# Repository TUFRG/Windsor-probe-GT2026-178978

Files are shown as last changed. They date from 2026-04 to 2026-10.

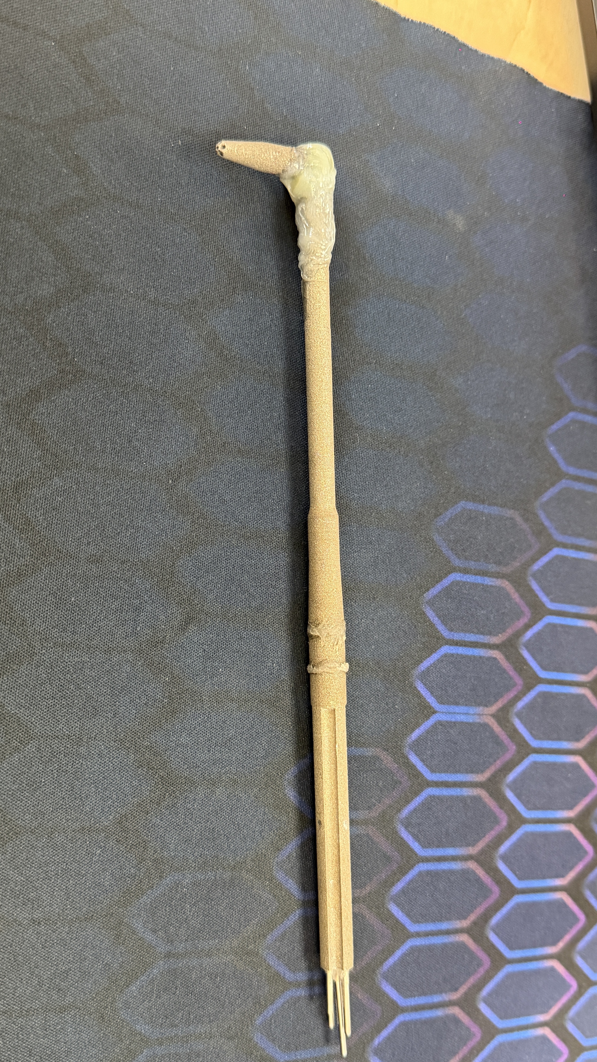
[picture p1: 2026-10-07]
Probe Calibration/Calibration Data and Map/ReMax On Axis Calibration - Use This/P2/Probe 2 Identifier.jpg

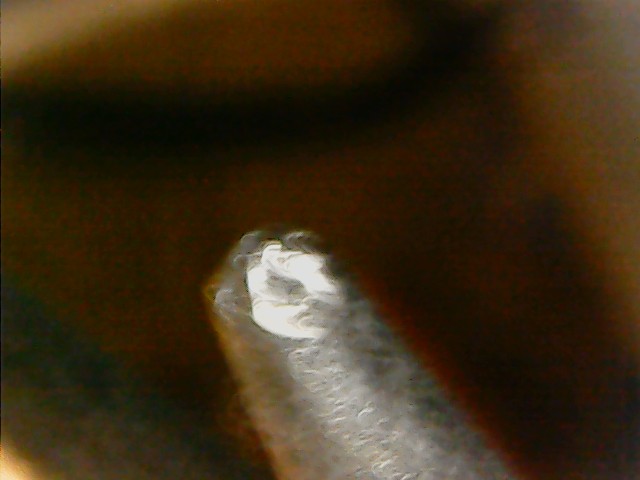
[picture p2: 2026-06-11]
Probe Design Files/Probe Assembly (CAT Parts and STL)/Digital Microscope Images/Probe 1 Photos/WIN_20260123_12_52_14_Pro.jpg

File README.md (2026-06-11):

# Windsor-probe-GT2026-178978

This repository contains openly available design and calibration files for the Windsor Probe—an L-shaped adaptation of the Oxford Probe head. The probe is an additively manufactured stainless steel five-hole probe featuring a 3mm probe head diameter, developed by Aman Thomson during his Masters degree with the Turbomachinery and Unsteady Flows Research Group, at the University of Windsor.

Probe calibration was performed using LabVIEW, with post-processing and data analysis conducted in Python, Excel, and MATLAB.

## Citing

Please cite the following paper, which details the design and calibration of the probe:

Thomson, A., Fontanin, L., and Defoe, J., “The Windsor Probe: An Additively Manufactured L-Shaped 5-Hole Probe Based on Oxford Probe Heads,” Proceedings of the ASME Turbo Expo, GT2026-178978, Milan, Italy, June 15–19, 2026.

## Contents

The repository is organized into three main folders: the first contains the probe design files, the second contains the calibration files, and the third contains the calibration facility design files together with the Bill of Materials (BOM).

### Probe Design Files

This section is organized into the following folders:

* **Drawings**

&#x09;  Includes detailed technical drawings for all probe components

* **Probe Assembly (CAT Parts and STL)**

&#x09;Provides individual CAD files for each probe component and the full assembly. This folder also includes high-resolution microscopic images of the assembled probe for inspection and reference.

&#x09;CAT Parts were designed in CATIA V5 6R-2021 and require the same or later version to open 

### Probe Calibration

This section is organized into the following folders:

* **Calibration Data and Map**

&#x09;Contains the raw data collected during the calibration process across multiple runs, covering Reynolds numbers ranging from 1000 to 4300 (based on probe diameter) and provides visual calibration maps along with the datasets used to generate them. Maps are available for all Reynolds numbers at which calibration was performed..

* **Calibration Facility**

&#x09;Includes CAD and assembly files for the calibration facility used to test the probe. The facility was designed using CATIA V5–6R2021.

* **Calibration Program (5 Hole Probe Calibration 2025)**

&#x09;Contains the LabVIEW VI and associated subVIs used during calibration. Developed and executed in LabVIEW 2023.

* **Processing Scripts**

&#x09;Includes sample Excel files (with formulas for calibration coefficient calculations), the experimental data structure, and scripts used for: Averaging repeated measurements, generating calibration maps and estimating measurement uncertainty

&#x09;Data averaging was performed using Python, while calibration map generation and uncertainty analysis were carried out in MATLAB.

### Calibration Facility and BOM

This section is organized into the following folders:

* **Calibration Facility**

&#x09;  Includes full CAD assembly of the calibration facility and detailed technical drawings for newly manufactured parts used to retrofit the existing calibration facility.

* **BOM (Bill of Materials)**

&#x09;  Contains a complete list of components used in the design, manufacturing, and calibration of the probe, including items required for the calibration facility.

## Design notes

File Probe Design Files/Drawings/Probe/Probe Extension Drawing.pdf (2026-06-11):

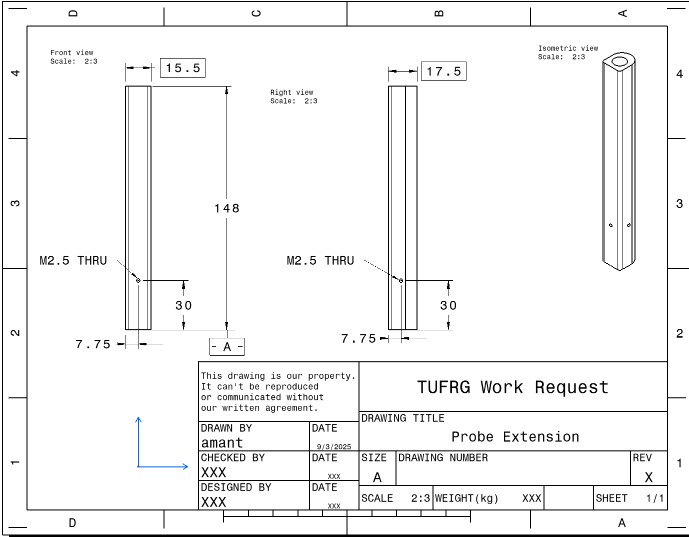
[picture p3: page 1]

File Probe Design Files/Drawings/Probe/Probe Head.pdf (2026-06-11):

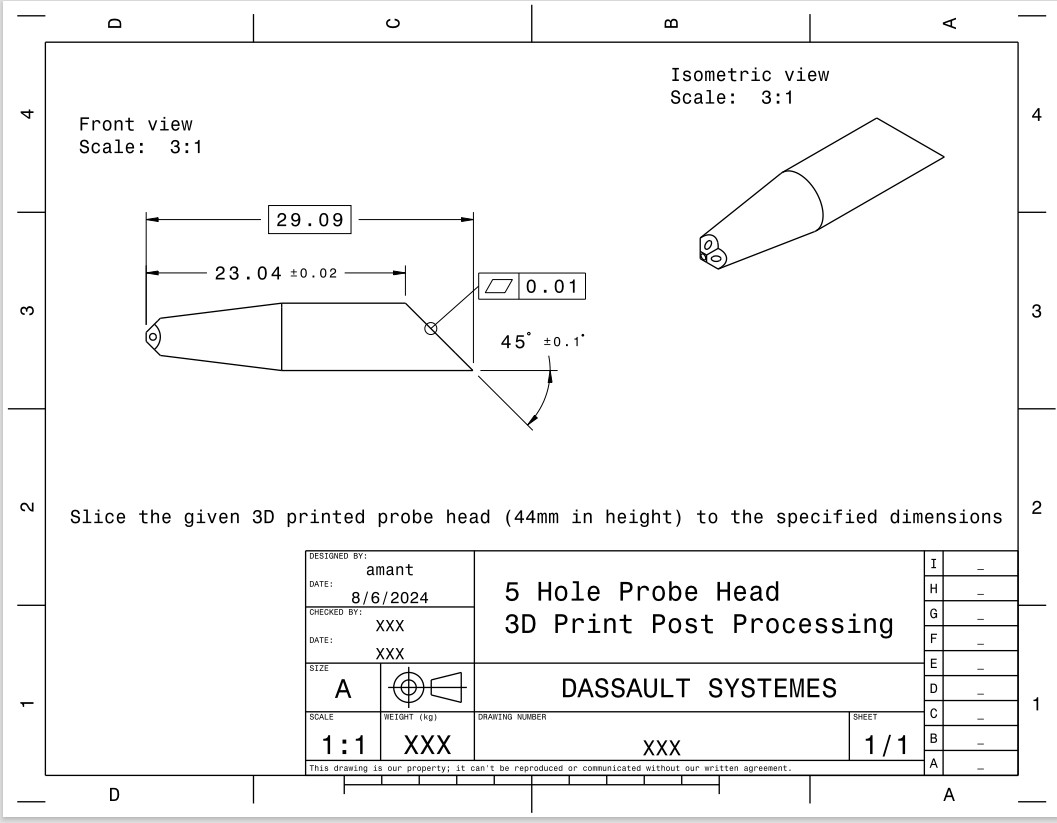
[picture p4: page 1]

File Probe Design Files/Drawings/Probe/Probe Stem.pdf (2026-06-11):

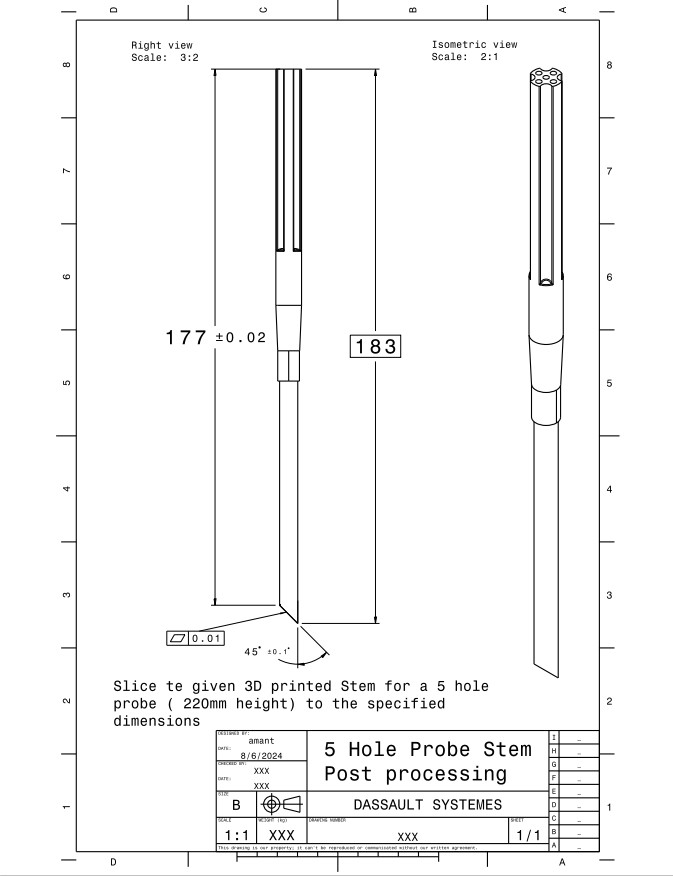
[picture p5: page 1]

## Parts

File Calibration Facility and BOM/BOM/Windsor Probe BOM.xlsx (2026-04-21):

Probe Components
 | Item No | Item | QTY. | Item Category | Vendor | Material
 | 1 | Probe Head | 3 | Custom designed & 3D printed and Wire EDM Cut | AMIC Mohawk College | 316L Stainless Steel
 | 2 | Probe Stem | 3 | Custom designed & 3D printed and Wire EDM Cut | AMIC Mohawk College | 316L Stainless Steel
 | 3 | Probe Extension | 3 | Custom designed & 3D printed and Wire EDM Cut | AMIC Mohawk College | 316L Stainless Steel
Probe Attachments
 | Item No | Item | QTY. | Item Category | Vendor | Material
 | 1 | Stainless Steel Tubulations 1.59mm OD | 15 | Off the Shelf | Scanivalve | Stainless Steel
 | 2 | Nylon Tubulation for 1.59mm OD tubes 400ft spool | 1 | Off the Shelf | Scanivalve | Nylon 6
 | 3 | Sealing adhesive | 3 | Off the Shelf | Canadian Tire | Cyanoacrylate
 | 4 | 2-Part Metal Epoxy gel | 1 | Off the Shelf | Canadian Tire | Epoxy
 | 5 | M2.5 Set screws | 12 | Off the Shelf | Mcmaster Carr | Zinc Plated Steel
Probe Calibration Facility
 | Item No | Item | QTY. | Item Category | Vendor | Material
 | 1 | Calibration Jet Nozzle | 1 | Custom designed & CNC Machined | University of Windsor | Aluminum
 | 2 | Horizontal Plate | 1 | Custom designed & CNC Machined | University of Windsor | Aluminum
 | 3 | Vertical Plate | 1 | Custom designed & CNC Machined | University of Windsor | Aluminum
 | 4 | Offset Block | 1 | Custom designed & CNC Machined | University of Windsor | Aluminum
 | 5 | Probe Holder Base | 1 | Custom designed & CNC Machined | University of Windsor | Aluminum
 | 6 | Probe Holder | 2 | Custom designed & CNC Machined | University of Windsor | Aluminum
 | 7 | Ref Probe Holder Base | 1 | Custom designed & CNC Machined | University of Windsor | Aluminum
 | 8 | Ref Probe Holder Verical Plate | 1 | Custom designed & CNC Machined | University of Windsor | Aluminum
 | 9 | Ref Probe Holder Bed | 1 | Custom designed & CNC Machined | University of Windsor | Aluminum
 | 10 | United Sensors PAC-12-KL Pitot Static Tube | 1 | Off the Shelf | United Sensors | Stainless Steel
 | 11 | DSA3217 Pressure Scanner | 1 | Off the Shelf | Scanivavle | N/A
Mechanical Fastening
 | Item No | Item | QTY./ PKG | Item Category | Vendor | Material
 | 1 | 90 Degree Countersink Angle, M3 x 0.50 mm Thread, 6 mm Long | 1 Pack of 100 | Off the Shelf | McMaster-Carr | Black-Oxide Alloy Steel
 | 2 | Socket Head Screw M3 x 0.5 mm Thread, 8 mm Long | 1 Pack of 50 | Off the Shelf | McMaster-Carr | Zinc-Flake-Coated Alloy Steel
 | 3 | Hex Nut Medium-Strength, Class 8, M3 x 0.5 mm Thread | 1 Pack of 100 | Off the Shelf | McMaster-Carr | Zinc-Plated Steel
 | 4 | Socket Head Screw Black-Oxide, M3 x 0.5 mm Thread, 30 mm Long, Fully Threaded | 1 Pack of 10 | Off the Shelf | McMaster-Carr | Alloy Steel
 | 5 | Socket Head Screw 10-32 Thread Size, 3" Long, Fully Threaded | 1 Pack of 10 | Off the Shelf | McMaster-Carr | Black-Oxide Alloy Steel
 | 6 | M2.5 x 0.45 mm Thread, 5 mm Long | 1 Pack of 50 | Off the Shelf | McMaster-Carr | 18-8 Stainless Steel
 | 7 | Socket Head Screw 10-32 Thread Size, 2-3/4" Long, Fully Threaded | 1 Pack of 10 | Off the Shelf | McMaster-Carr | Black-Oxide Alloy Steel
 | 8 | Socket Head Screw 1/4"-20 Thread Size, 5/8" Long | 1 Pack of 50 | Off the Shelf | McMaster-Carr | Black-Oxide Alloy Steel
 | 9 | Socket Head Screw M5 x 0.8 mm Thread, 18 mm Long | 1 Pack of 100 | Off the Shelf | McMaster-Carr | Alloy Steel
 | 10 | Socket Head Screw 10-32 Thread Size, 7/8" Long | 1 Pack of 10 | Off the Shelf | McMaster-Carr | Black-Oxide Alloy Steel
 | 11 | Socket Head Screw 10-32 Thread Size, 1-1/4" Long, Fully Threaded | 1 Pack of 50 | Off the Shelf | McMaster-Carr | 18-8 Stainless Steel
 | 12 | Socket Head Screw Black-Oxide, M4 x 0.7 mm Thread, 8 mm Long | 1 Pack of 100 | Off the Shelf | McMaster-Carr | Alloy Steel
 | 13 | Dowel Pin, 2 mm Diameter, 10 mm Long | 1 Pack of 50 | Off the Shelf | McMaster-Carr | Alloy Steel
 | 14 | High-Strength Class 10 Flange Nut Standard Profile, M5 x 0.8 mm Thread | 1 Pack of 25 | Off the Shelf | McMaster-Carr | Zinc Plated Steel
 | 15 | Hex Nut, 10-32 Thread Size | 1 Pack of 50 | Off the Shelf | McMaster-Carr | Zinc Plated Steel

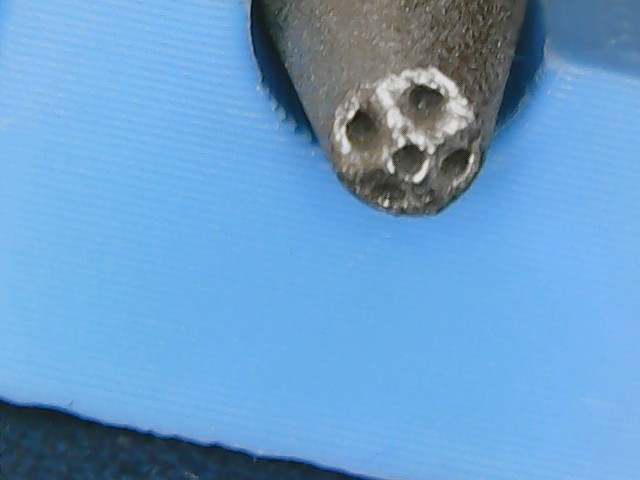
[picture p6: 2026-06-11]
Probe Design Files/Probe Assembly (CAT Parts and STL)/Digital Microscope Images/Close up probe head/WIN_20260123_12_09_09_Pro.jpg

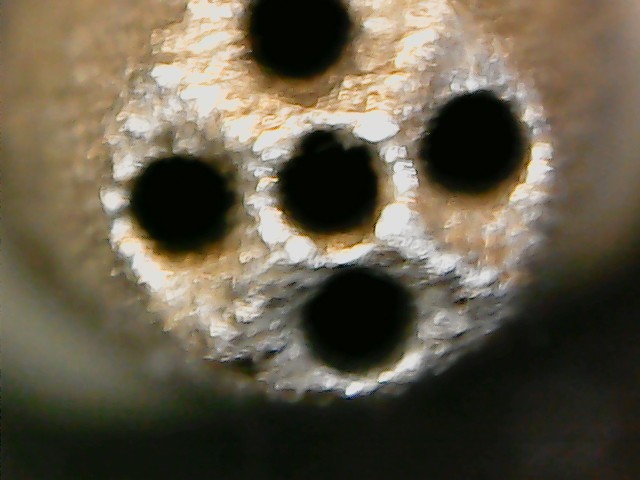
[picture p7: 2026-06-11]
Probe Design Files/Probe Assembly (CAT Parts and STL)/Digital Microscope Images/Close up probe head/WIN_20260604_11_44_16_Pro.jpg

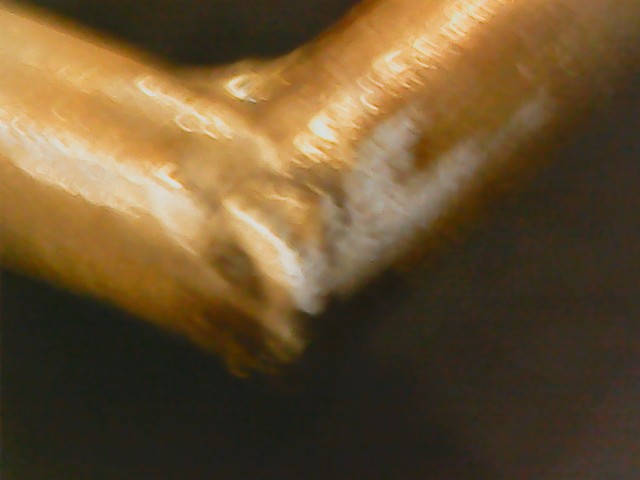
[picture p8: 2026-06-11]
Probe Design Files/Probe Assembly (CAT Parts and STL)/Digital Microscope Images/Probe 1 Photos/WIN_20260123_12_42_23_Pro.jpg

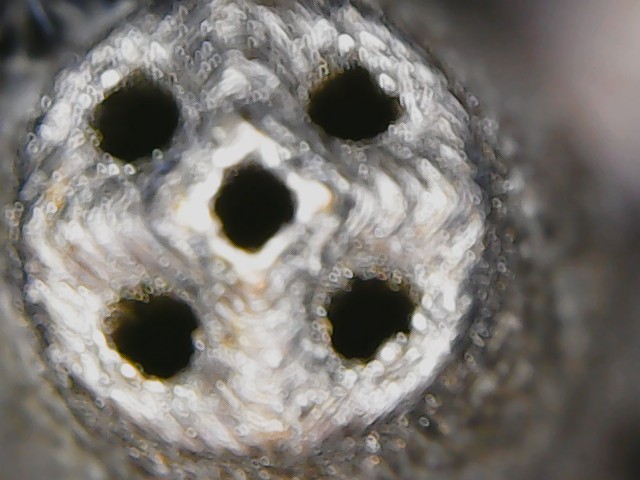
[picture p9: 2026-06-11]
Probe Design Files/Probe Assembly (CAT Parts and STL)/Digital Microscope Images/Probe 1 Photos/WIN_20260123_12_46_40_Pro.jpg

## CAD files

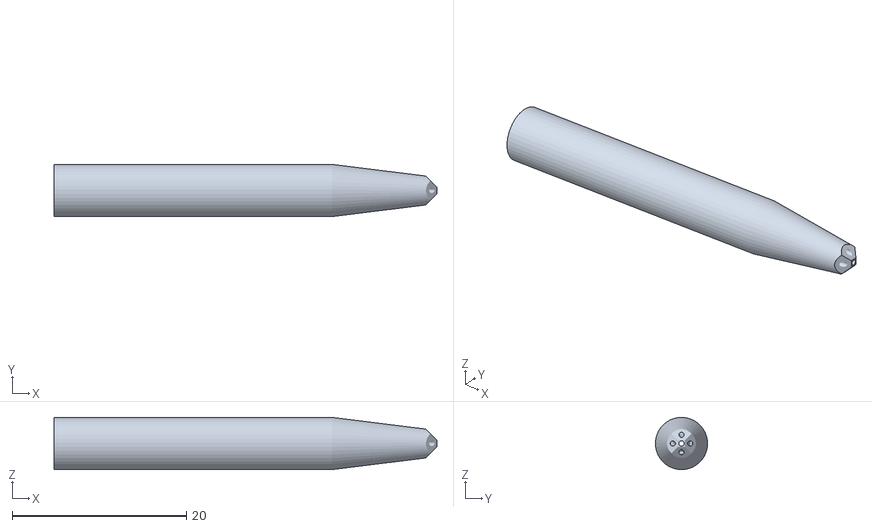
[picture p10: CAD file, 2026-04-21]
Probe Design Files/Probe Assembly (CAT Parts and STL)/Probe Head- Extended.stl
44.0 x 6.00 x 6.00

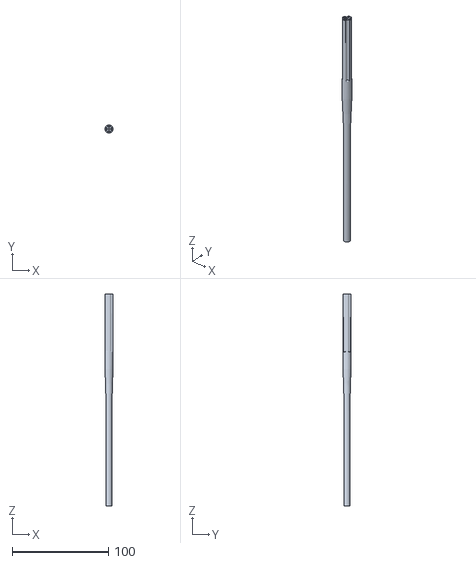
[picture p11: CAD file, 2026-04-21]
Probe Design Files/Probe Assembly (CAT Parts and STL)/Stem Chuck - Extended.stl
8.50 x 8.50 x 220.0

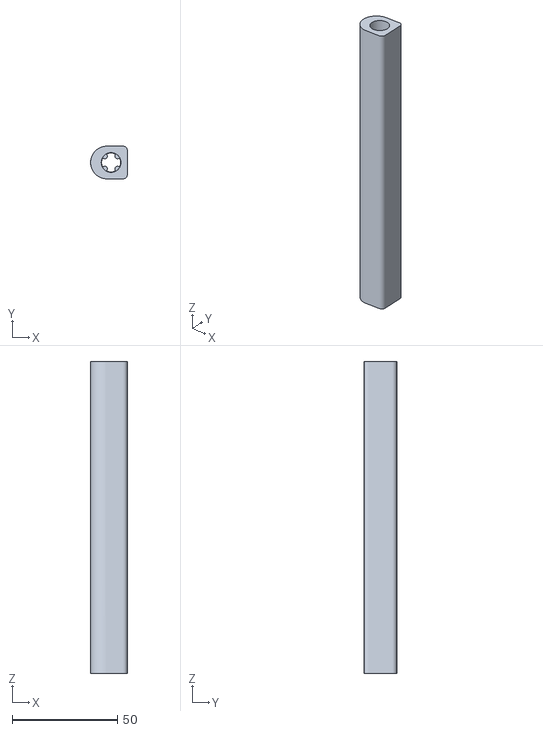
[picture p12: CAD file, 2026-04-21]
Probe Design Files/Probe Assembly (CAT Parts and STL)/Probe Extension.stl
17.5 x 15.5 x 148.3

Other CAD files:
Calibration Facility and BOM/Calibration Facility/CAD Assembly/5Hole_Probe_Holder_New_L.CATPart
Calibration Facility and BOM/Calibration Facility/CAD Assembly/5Hole_Probe_Holder_New_R.CATPart
Calibration Facility and BOM/Calibration Facility/CAD Assembly/5_Hole_Probe_Assembly.CATProduct
Calibration Facility and BOM/Calibration Facility/CAD Assembly/5_Hole_Probe_Extension_Rig.CATPart
Calibration Facility and BOM/Calibration Facility/CAD Assembly/5_Hole_Probe_Head.CATPart
Calibration Facility and BOM/Calibration Facility/CAD Assembly/5_Hole_Probe_LStem_EXT_Combined_Part.CATPart
Calibration Facility and BOM/Calibration Facility/CAD Assembly/5_hole_probe_Holder_New.CATProduct
Calibration Facility and BOM/Calibration Facility/CAD Assembly/B4800TS.CATPart
Calibration Facility and BOM/Calibration Facility/CAD Assembly/BAse.CATPart
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

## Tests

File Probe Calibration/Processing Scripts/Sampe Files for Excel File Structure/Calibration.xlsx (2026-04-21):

P1 | P2 | P3 | P4 | P5 | Pstatic | Ptot | Alpha | Beta | rho | v | Calpha | Cbeta | Cp | Cp0
73.349987 | -436.0425492 | -453.3598175 | 182.3264773 | -209.5928343 | 6.57809375 | 312.4402698 | 44 | 53.31764151 | 1.15 | 23.06367675 | 2.240298367 | -2.630221873 | -2.220468444 | -1.919492656
74.6590025 | -398.8100738 | -419.2774582 | 200.598549 | -176.7976302 | 6.57809425 | 305.596741 | 44 | 49.39431492 | 1.15 | 22.804219 | 2.126893675 | -2.581059163 | -2.07726688 | -1.789663774
74.88469125 | -369.8781282 | -389.780098 | 217.9066465 | -149.3428725 | 6.3831875 | 301.1945035 | 44 | 45.28541913 | 1.15 | 22.6432175 | 2.016075637 | -2.550300772 | -1.954852057 | -1.675710564
73.39512625 | -348.3830643 | -359.4708787 | 234.5574607 | -127.023119 | 6.0908285 | 299.9138485 | 44 | 40.97988699 | 1.15 | 22.60523275 | 1.907809151 | -2.569240078 | -1.881751227 | -1.586742922
68.2042045 | -328.9282457 | -323.9748308 | 250.507198 | -107.8893662 | 6.0916865 | 299.033386 | 44 | 36.47044446 | 1.15 | 22.57130475 | 1.794392086 | -2.651191004 | -1.861906169 | -1.521539746
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

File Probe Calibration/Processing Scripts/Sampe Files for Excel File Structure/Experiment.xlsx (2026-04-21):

P1 | P2 | P3 | P4 | P5 | Pstatic | Ptot
73.349987 | -436.0425492 | -453.3598175 | 182.3264773 | -209.5928343 | 6.57809375 | 312.4402698
74.6590025 | -398.8100738 | -419.2774582 | 200.598549 | -176.7976302 | 6.57809425 | 305.596741
74.88469125 | -369.8781282 | -389.780098 | 217.9066465 | -149.3428725 | 6.3831875 | 301.1945035
73.39512625 | -348.3830643 | -359.4708787 | 234.5574607 | -127.023119 | 6.0908285 | 299.9138485
68.2042045 | -328.9282457 | -323.9748308 | 250.507198 | -107.8893662 | 6.0916865 | 299.033386
57.14527975 | -311.373451 | -282.840889 | 258.4820635 | -92.81429275 | 5.8975965 | 293.7106473
43.558605 | -296.091545 | -239.1360932 | 268.9983673 | -79.07724175 | 6.042102 | 292.149872
27.1282085 | -284.7978973 | -197.5962295 | 274.8261415 | -67.168827 | 5.89715375 | 290.1088025
7.267288 | -275.5781555 | -155.470024 | 277.1923215 | -58.20406325 | 5.45853225 | 285.8666533
-16.850871 | -269.3996045 | -114.336094 | 279.2955857 | -51.1125345 | 5.7509605 | 284.619026
-44.6953565 | -264.8719863 | -76.35937475 | 277.4552307 | -46.78625575 | 5.5564145 | 281.0967865
-76.144306 | -272.1629257 | -43.07336225 | 285.123375 | -42.905983 | 5.800116 | 288.604828
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

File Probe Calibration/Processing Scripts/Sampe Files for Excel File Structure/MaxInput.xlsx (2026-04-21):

C _alpha | C_beta | C p0 | Cp
2.240298367 | -2.630221873 | -2.220468444 | -1.919492656
2.126893675 | -2.581059163 | -2.07726688 | -1.789663774
2.016075637 | -2.550300772 | -1.954852057 | -1.675710564
1.907809151 | -2.569240078 | -1.881751227 | -1.586742922
1.794392086 | -2.651191004 | -1.861906169 | -1.521539746
1.66421853 | -2.78949602 | -1.892099166 | -1.483230635
1.499438533 | -2.997407985 | -1.969153537 | -1.451530506
1.291285167 | -3.215766669 | -2.053031451 | -1.419860003
1.034485445 | -3.5138196 | -2.187221374 | -1.404749355
0.6925738112 | -3.898332928 | -2.385303802 | -1.404031293
0.2555612874 | -4.380038626 | -2.648182977 | -1.422798052
-0.251904086 | -4.24632063 | -2.526001201 | -1.371156803
-0.6566610312 | -3.706259943 | -2.189113087 | -1.328204073
-0.9520504158 | -3.312154489 | -1.958858799 | -1.295395563
-1.187899853 | -3.019665779 | -1.80050197 | -1.295461631
-1.381952633 | -2.795804142 | -1.702486105 | -1.301609727
-1.552448419 | -2.638655684 | -1.66044441 | -1.330589365
-1.697509436 | -2.550168845 | -1.665383892 | -1.387893593
-1.823264059 | -2.486719208 | -1.6864729 | -1.453144981
-1.968887453 | -2.519393771 | -1.802367279 | -1.563451884
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

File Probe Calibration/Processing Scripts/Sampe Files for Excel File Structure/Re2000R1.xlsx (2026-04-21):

P1 (Top) | P2 (Left) | P3 (Bottom) | P4 (Right) | P5 (Center) | Pstatic (P) | Ptot_ref (P0) | Alpha | Beta | Density | Flow Velocity | C Alpha | C Beta | C p0 | Cp
18.7815 | -107.091454 | -114.772072 | 51.501125 | -55.497784 | 1.169333 | 86.459656 | -44 | -44 | 1.18 | 12.023305 | 2.409 | -2.861 | -2.561 | -2.022
18.7815 | -107.475288 | -114.95253 | 51.6763 | -55.140877 | 1.169333 | 86.459656 | -44 | -44 | 1.18 | 12.023305 | 2.385 | -2.838 | -2.525 | -2.004
18.78145 | -107.283371 | -114.95253 | 51.689384 | -54.962433 | 1.364229 | 86.459541 | -44 | -44 | 1.18 | 12.009552 | 2.381 | -2.831 | -2.518 | -2.003
18.7815 | -107.475288 | -115.67437 | 51.6763 | -55.497784 | 1.364229 | 86.459541 | -44 | -44 | 1.18 | 12.009552 | 2.398 | -2.838 | -2.531 | -2.014
18.7815 | -103.444969 | -111.523804 | 58.332905 | -49.965851 | 1.169333 | 87.260208 | -44 | -40 | 1.18 | 12.0796 | 2.265 | -2.813 | -2.386 | -1.889
19.503864 | -102.485359 | -110.621506 | 57.982555 | -49.4305 | 1.169333 | 87.260208 | -44 | -40 | 1.18 | 12.0796 | 2.278 | -2.809 | -2.393 | -1.886
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

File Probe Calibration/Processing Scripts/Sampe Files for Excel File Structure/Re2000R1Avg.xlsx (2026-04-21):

P1 (Top) | P2 (Left) | P3 (Bottom) | P4 (Right) | P5 (Center) | Pstatic (P) | Ptot_ref (P0) | Alpha | Beta | Density | Flow Velocity | C Alpha | C Beta | C p0 | Cp
18.7814875 | -107.3313502 | -115.0878755 | 51.63577725 | -55.2747195 | 1.266781 | 86.4595985 | -44 | -44 | 1.18 | 12.0164285 | 2.393356495 | -2.842060929 | -2.533998398 | -2.010880171
19.1878295 | -103.3010252 | -111.5238057 | 58.20152475 | -50.01046075 | 1.218057 | 87.30023575 | -44 | -40 | 1.18 | 12.07899 | 2.277137629 | -2.813549903 | -2.392115414 | -1.892453286
19.77475075 | -99.22272275 | -105.658878 | 63.89467825 | -44.12162975 | 1.2667985 | 87.90065 | -44 | -36 | 1.18 | 12.1176315 | 2.150876966 | -2.797068542 | -2.263906942 | -1.778319991
19.18783 | -94.47269475 | -96.2750015 | 69.98643275 | -37.474387 | 1.36423725 | 88.34095925 | -44 | -32 | 1.18 | 12.1415805 | 1.994212374 | -2.840432056 | -2.173013258 | -1.670795103
16.704698 | -91.3539945 | -87.6580715 | 74.633606 | -33.99462325 | 1.266816 | 89.2215845 | -44 | -28 | 1.18 | 12.20966175 | 1.88008899 | -2.990341648 | -2.219860817 | -1.635308863
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

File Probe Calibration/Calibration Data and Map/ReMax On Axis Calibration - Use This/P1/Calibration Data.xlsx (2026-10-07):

Alpha | Beta | Density | Flow Velocity | C Alpha | C Beta | C p0 | Cp
44 | 53.31764151 | 1.153333333 | 21.61512325 | 2.16492105 | -2.547043459 | -2.082238629 | -1.801006787
44 | 49.39431492 | 1.1525 | 22.17354675 | 2.034285859 | -2.473796906 | -1.91327192 | -1.667907175
44 | 45.28541913 | 1.153333333 | 22.77548458 | 1.916001126 | -2.454046799 | -1.796356797 | -1.562141309
44 | 40.97988699 | 1.153333333 | 23.34179733 | 1.809159715 | -2.495858739 | -1.747746325 | -1.48462097
44 | 36.47044446 | 1.153333333 | 23.70778275 | 1.683353392 | -2.598067686 | -1.742335917 | -1.426332614
44 | 31.7550514 | 1.153333333 | 23.66966425 | 1.535720016 | -2.741878672 | -1.774527742 | -1.380645951
44 | 26.83841444 | 1.153333333 | 23.19917833 | 1.365545317 | -2.926340543 | -1.838818813 | -1.340622944
44 | 21.73336293 | 1.153333333 | 22.30078425 | 1.141600236 | -3.18023761 | -1.947421981 | -1.318125936
44 | 16.46179842 | 1.153333333 | 21.71479083 | 0.8611417711 | -3.486940522 | -2.090431888 | -1.302939859
44 | 11.05489267 | 1.153333333 | 21.78099875 | 0.5073967952 | -3.816626803 | -2.240802258 | -1.278977927
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

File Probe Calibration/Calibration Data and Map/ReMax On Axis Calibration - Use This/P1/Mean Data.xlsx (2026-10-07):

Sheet: Sheet1
Alpha | Beta | Density | Flow Velocity | C Alpha | C Beta | C p0 | Cp | Re | C Alpha | C Beta | C p0 | Cp
44 | 53.31764151 | 1.153333333 | 21.61512325 | 2.16492105 | -2.547043459 | -2.082238629 | -1.801006787 | 4154.907025 | 0.005160344288 | 0.004921524299 | 0.006740725334 | 0.004380979481 | 0.1088234755 | 0.04661825332 | 0.09185650952 | 0.03582109739
44 | 49.39431492 | 1.1525 | 22.17354675 | 2.034285859 | -2.473796906 | -1.91327192 | -1.667907175 | 4259.168772 | 0.008607970074 | 0.006992918766 | 0.0123861595 | 0.006992870742 | 0.0004130452219 | 0.0001778369313 | 0.0002211647331 | 0.0001863573702
44 | 45.28541913 | 1.153333333 | 22.77548458 | 1.916001126 | -2.454046799 | -1.796356797 | -1.562141309 | 4377.954259 | 0.0042087267 | 0.003059159186 | 0.006277273546 | 0.005148210959 | 0.006020610235 | 0.006885416753 | 0.006959885093 | 0.004266434806
44 | 40.97988699 | 1.153333333 | 23.34179733 | 1.809159715 | -2.495858739 | -1.747746325 | -1.48462097 | 4486.812154 | 0.005591364164 | 0.004777877685 | 0.004289716232 | 0.004807917974
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

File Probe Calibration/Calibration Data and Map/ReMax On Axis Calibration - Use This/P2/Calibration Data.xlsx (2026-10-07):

Alpha | Beta | Density | Flow Velocity | C Alpha | C Beta | C p0 | Cp
44 | 53.31764151 | 1.18 | 22.38251558 | 2.039372543 | -2.454321614 | -1.953788319 | -1.786111162
44 | 49.39431492 | 1.18 | 22.96625708 | 1.903644793 | -2.345621924 | -1.751945496 | -1.634488718
44 | 45.28541913 | 1.18 | 23.44456842 | 1.794921131 | -2.298894763 | -1.627246617 | -1.514292016
44 | 40.97988699 | 1.18 | 23.42732083 | 1.675112066 | -2.297255887 | -1.539192812 | -1.414398391
44 | 36.47044446 | 1.18 | 22.47517483 | 1.544643058 | -2.321769981 | -1.478245203 | -1.325811811
44 | 31.7550514 | 1.18 | 21.75778358 | 1.400577893 | -2.375130225 | -1.437939311 | -1.252259079
44 | 26.83841444 | 1.18 | 21.11572758 | 1.246783596 | -2.472855825 | -1.431044566 | -1.198123467
44 | 21.73336293 | 1.18 | 21.44613183 | 1.075505878 | -2.574866742 | -1.432246794 | -1.146110899
44 | 16.46179842 | 1.18 | 22.21970367 | 0.8867277994 | -2.691168144 | -1.441995467 | -1.102000665
44 | 11.05489267 | 1.18 | 22.8590235 | 0.6680993344 | -2.872202367 | -1.505003158 | -1.078543976
44 | 5.552260734 | 1.18 | 23.37225117 | 0.4132721216 | -3.124271675 | -1.625405701 | -1.078859599
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

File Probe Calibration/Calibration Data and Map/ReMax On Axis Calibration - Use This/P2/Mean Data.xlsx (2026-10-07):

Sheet: Sheet1
Alpha | Beta | Density | Flow Velocity | C Alpha | C Beta | C p0 | Cp | Re | C Alpha | C Beta | C p0 | Cp
44 | 53.31764151 | 1.18 | 22.38251558 | 2.039372543 | -2.454321614 | -1.953788319 | -1.786111162 | 4401.894731 | 0.004980863653 | 0.003754386274 | 0.006084594602 | 0.002725023517 | 0.02559067309 | 0.03349758769 | 0.04734869573 | 0.02229668279
44 | 49.39431492 | 1.18 | 22.96625708 | 1.903644793 | -2.345621924 | -1.751945496 | -1.634488718 | 4516.697226 | 0.007644035115 | 0.006659781539 | 0.007179782917 | 0.006259887997 | 9.491606774e-05 | 0.0002039326018 | 0.0001267418004 | 0.0001066623376
44 | 45.28541913 | 1.18 | 23.44456842 | 1.794921131 | -2.298894763 | -1.627246617 | -1.514292016 | 4610.765122 | 0.003647073649 | 0.005465398598 | 0.005136529661 | 0.004763839996 | 0.004502557467 | 0.004743019817 | 0.004214523502 | 0.003688258692
44 | 40.97988699 | 1.18 | 23.42732083 | 1.675112066 | -2.297255887 | -1.539192812 | -1.414398391 | 4607.373097 | 0.003486636846 | 0.006803984298 | 0.006659100325 | 0.00258328555
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

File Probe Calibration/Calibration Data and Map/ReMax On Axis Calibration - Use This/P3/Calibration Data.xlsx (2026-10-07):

Alpha | Beta | Density | Flow Velocity | C Alpha | C Beta | C p0 | Cp
44 | 53.31764151 | 1.16 | 21.44181933 | 2.253314785 | -2.463644877 | -2.087573212 | -1.829759068
44 | 49.39431492 | 1.173333333 | 21.95033758 | 2.089411608 | -2.328948294 | -1.819144506 | -1.654931799
44 | 45.28541913 | 1.173333333 | 22.57603133 | 1.972020581 | -2.227311679 | -1.633330363 | -1.517894726
44 | 40.97988699 | 1.174166667 | 23.162023 | 1.824667844 | -2.177974617 | -1.492342873 | -1.40473253
44 | 36.47044446 | 1.176666667 | 23.49255233 | 1.688979048 | -2.20114957 | -1.415377648 | -1.327017113
44 | 31.7550514 | 1.176666667 | 23.150246 | 1.563867786 | -2.232542539 | -1.358436808 | -1.254413829
44 | 26.83841444 | 1.176666667 | 22.26428717 | 1.429767481 | -2.310860845 | -1.344955453 | -1.200171679
44 | 21.73336293 | 1.176666667 | 21.51129975 | 1.299229519 | -2.416392238 | -1.361843483 | -1.156949061
44 | 16.46179842 | 1.176666667 | 21.44508508 | 1.141807521 | -2.551205986 | -1.398153725 | -1.122710441
44 | 11.05489267 | 1.176666667 | 21.74945092 | 0.950288567 | -2.694039388 | -1.438153442 | -1.095919635
44 | 5.552260734 | 1.176666667 | 22.35952958 | 0.731179318 | -2.88739516 | -1.515857508 | -1.088972958
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

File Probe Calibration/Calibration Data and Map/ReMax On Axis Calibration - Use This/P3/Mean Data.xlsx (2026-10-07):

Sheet: Sheet1
Alpha | Beta | Density | Flow Velocity | C Alpha | C Beta | C p0 | Cp | Re | C Alpha | C Beta | C p0 | Cp
44 | 53.31764151 | 1.16 | 21.44181933 | 2.253314785 | -2.463644877 | -2.087573212 | -1.829759068 | 4145.418404 | 0.01265296176 | 0.03464292717 | 0.03007413585 | 0.01619039962 | 0.03249830443 | 0.03464292717 | 0.03007413585 | 0.01665361499
44 | 49.39431492 | 1.173333333 | 21.95033758 | 2.089411608 | -2.328948294 | -1.819144506 | -1.654931799 | 4292.510461 | 0.002239915276 | 0.0194352114 | 0.0150892951 | 0.006555045098 | 0.0002652450482 | 0.0002322690699 | 0.0001265667334 | 0.0001616697696
44 | 45.28541913 | 1.173333333 | 22.57603133 | 1.972020581 | -2.227311679 | -1.633330363 | -1.517894726 | 4414.86835 | 0.003786718575 | 0.001246431164 | 0.002108063969 | 0.00196986316 | 0.006603419591 | 0.008207061917 | 0.005277132115 | 0.004354724781
44 | 40.97988699 | 1.174166667 | 23.162023 | 1.824667844 | -2.177974617 | -1.492342873 | -1.40473253 | 4532.679223 | 0.006484211156 | 0.01843627617 | 0.006243199882 | 0.004334300959
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

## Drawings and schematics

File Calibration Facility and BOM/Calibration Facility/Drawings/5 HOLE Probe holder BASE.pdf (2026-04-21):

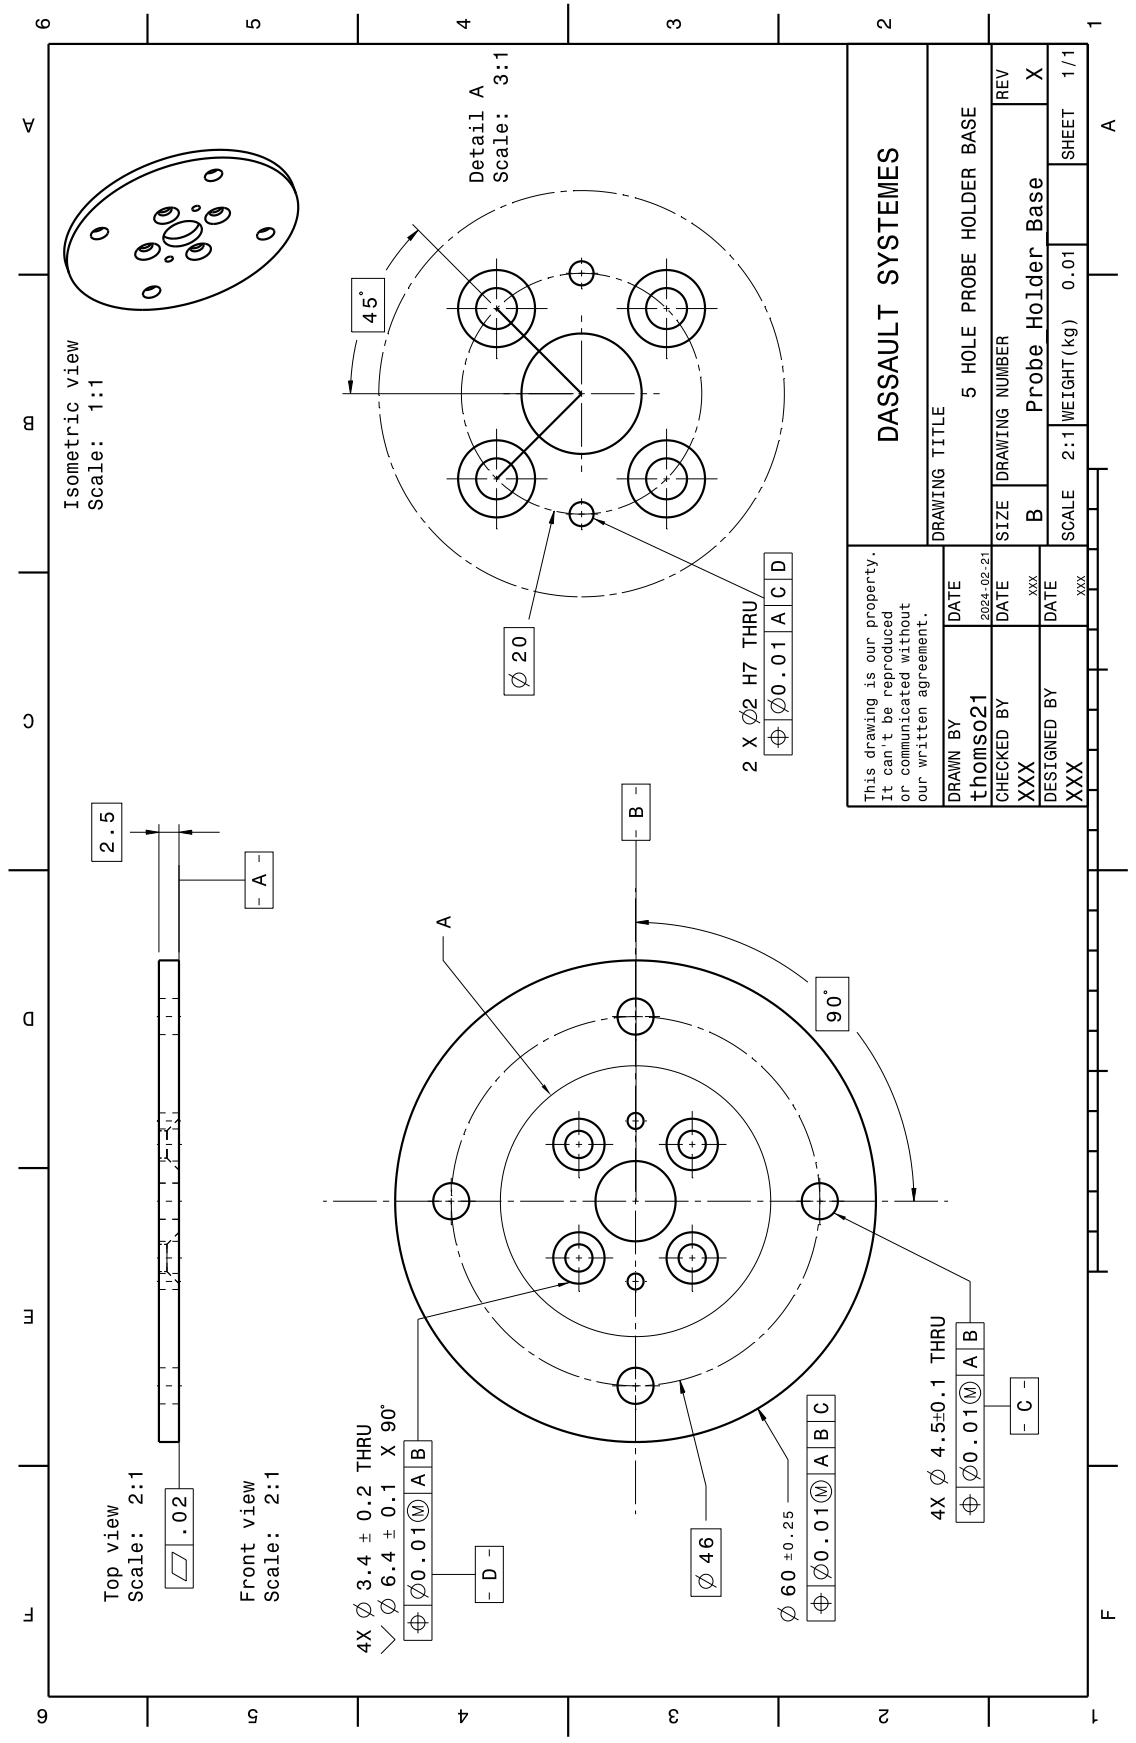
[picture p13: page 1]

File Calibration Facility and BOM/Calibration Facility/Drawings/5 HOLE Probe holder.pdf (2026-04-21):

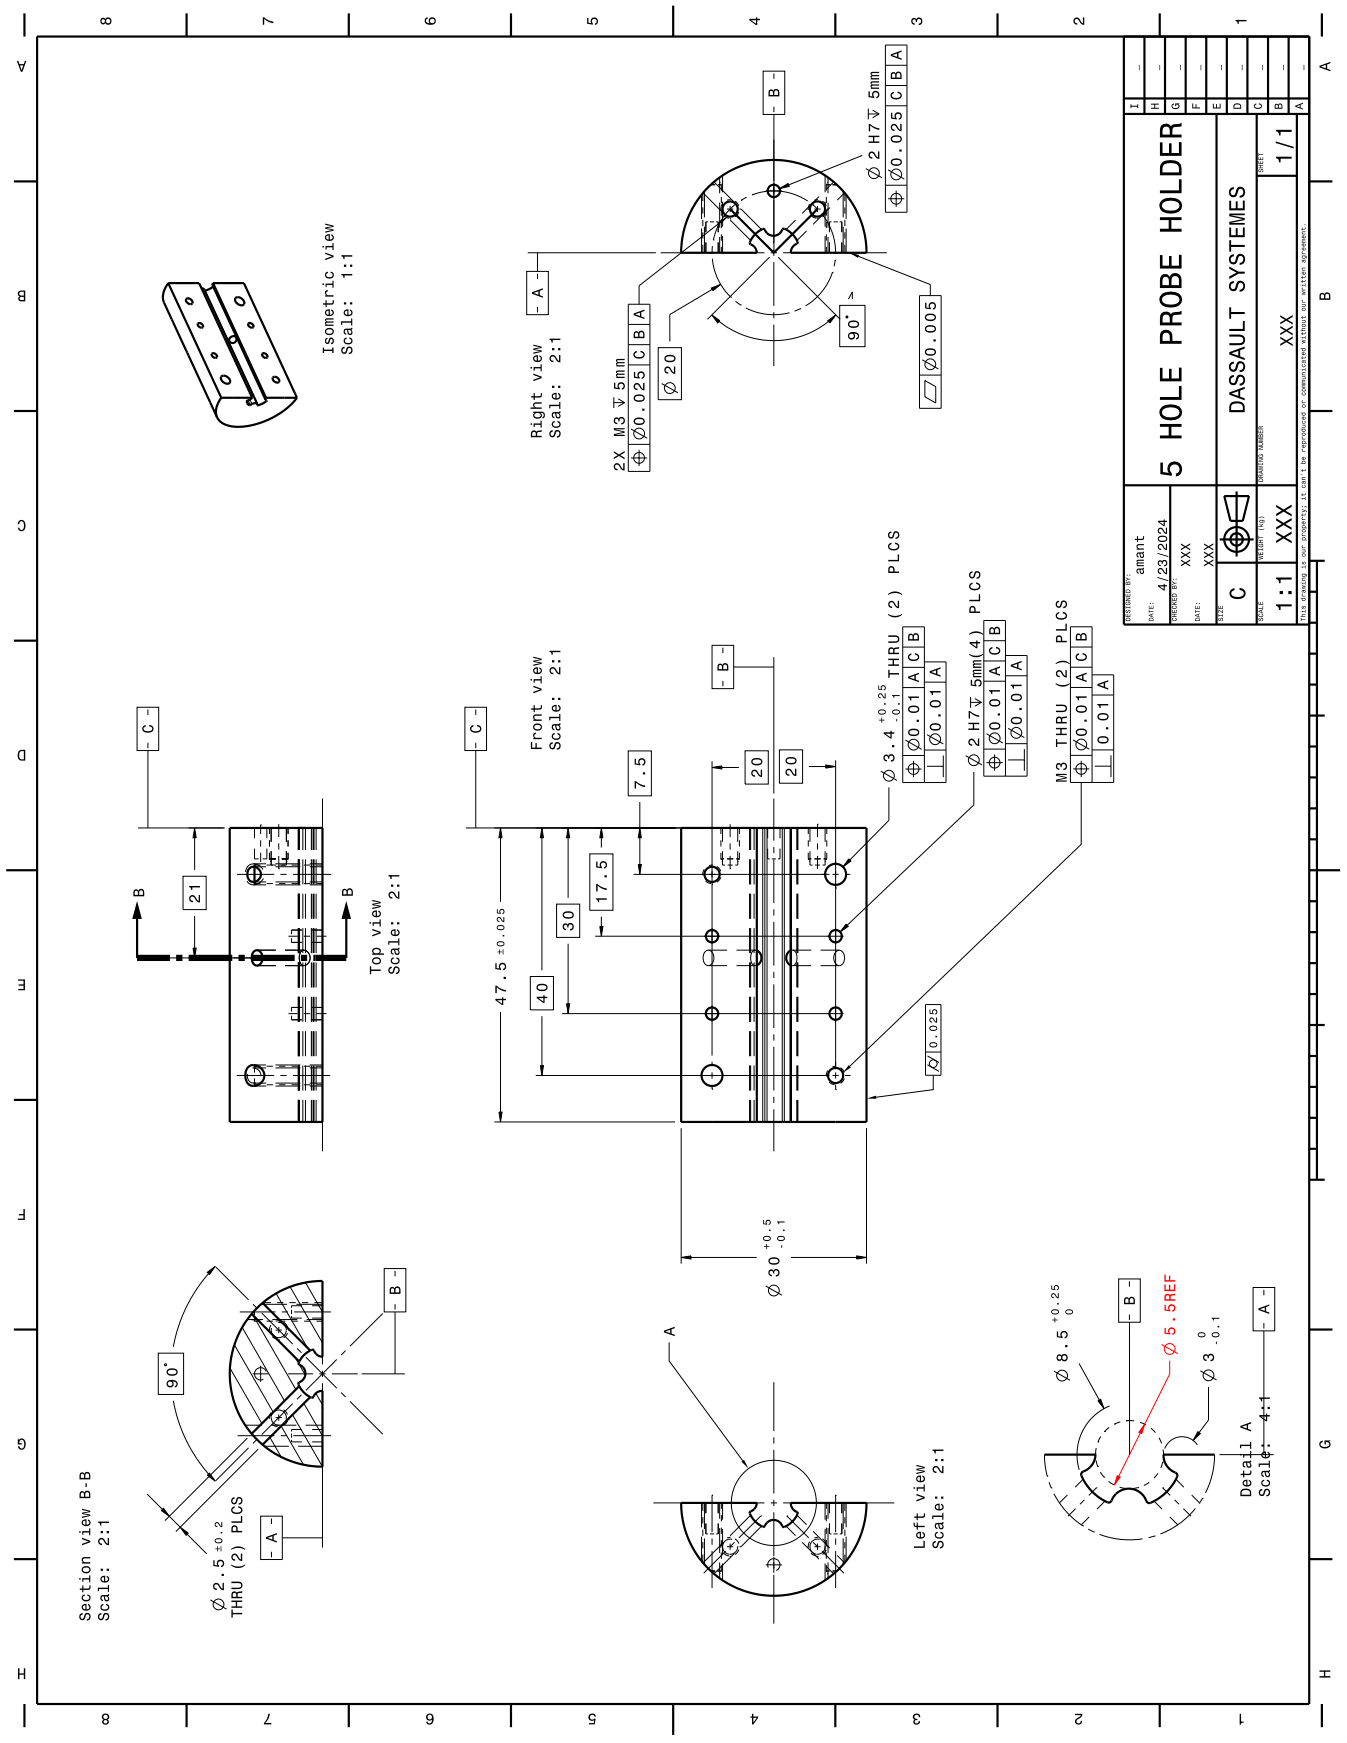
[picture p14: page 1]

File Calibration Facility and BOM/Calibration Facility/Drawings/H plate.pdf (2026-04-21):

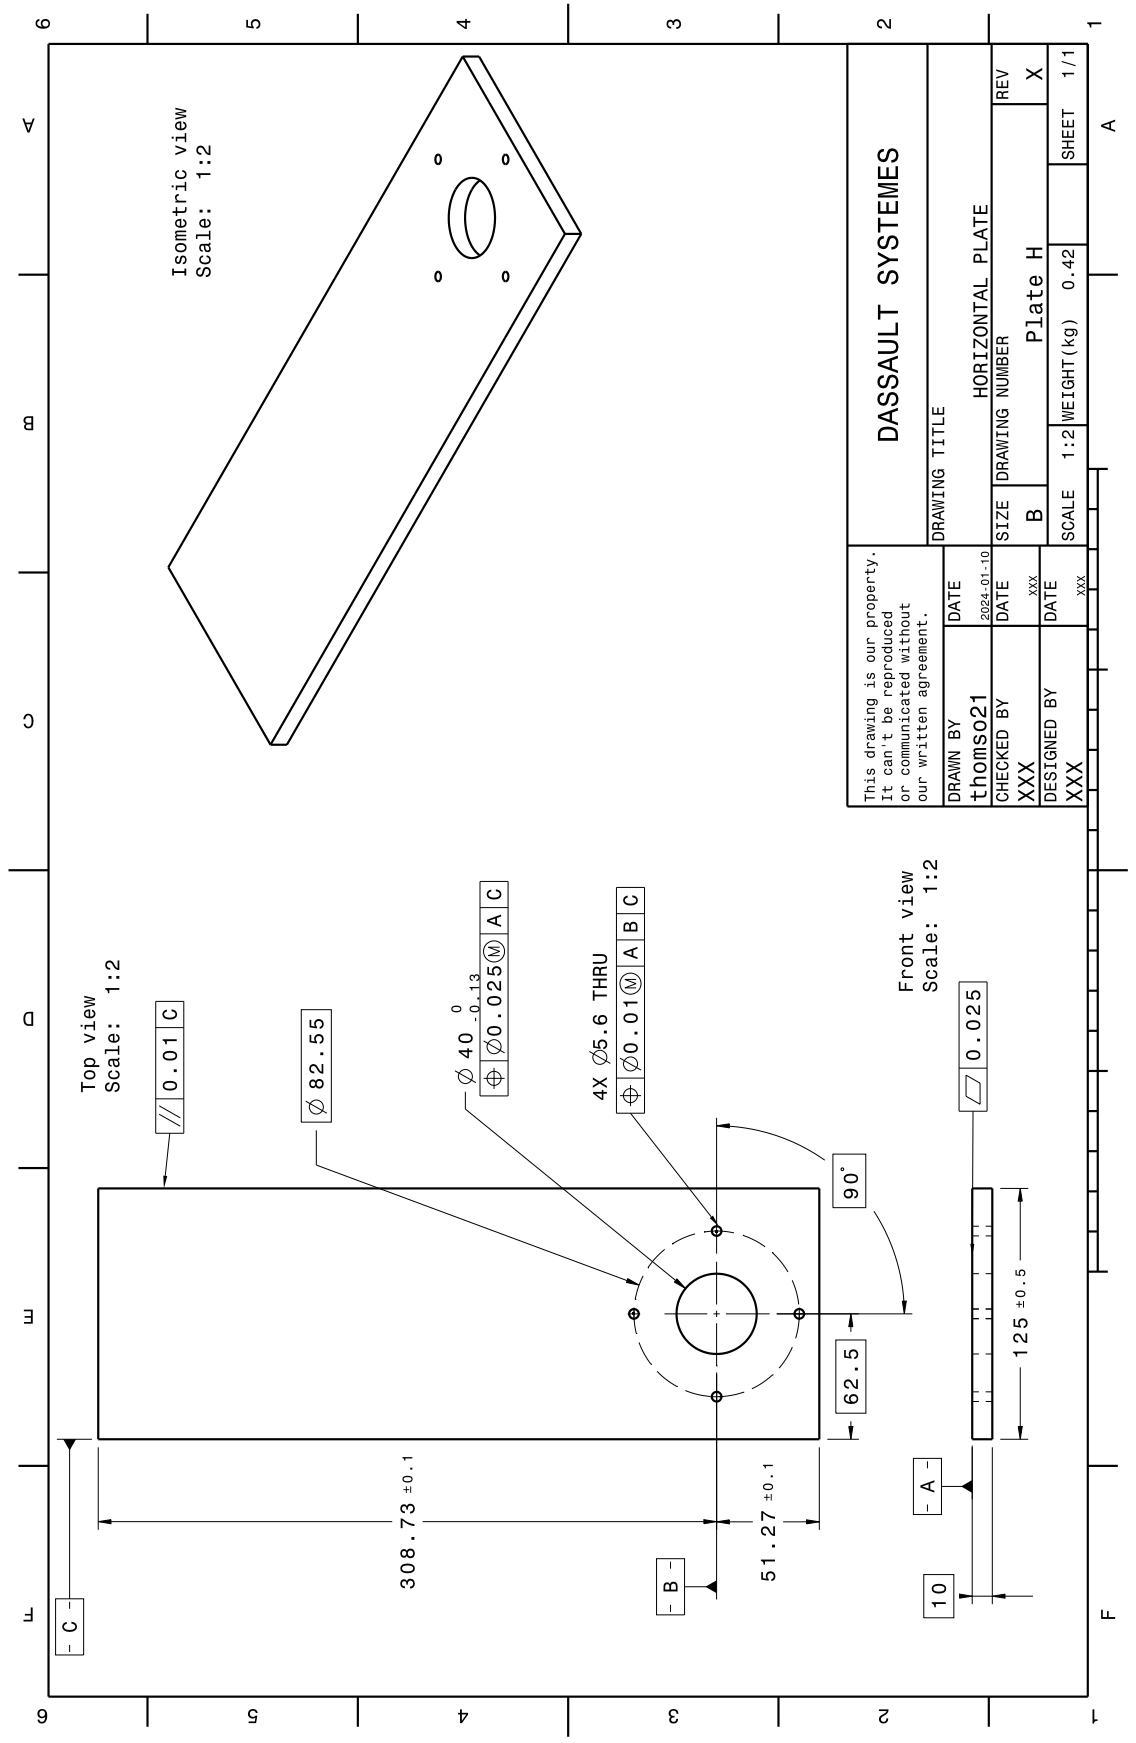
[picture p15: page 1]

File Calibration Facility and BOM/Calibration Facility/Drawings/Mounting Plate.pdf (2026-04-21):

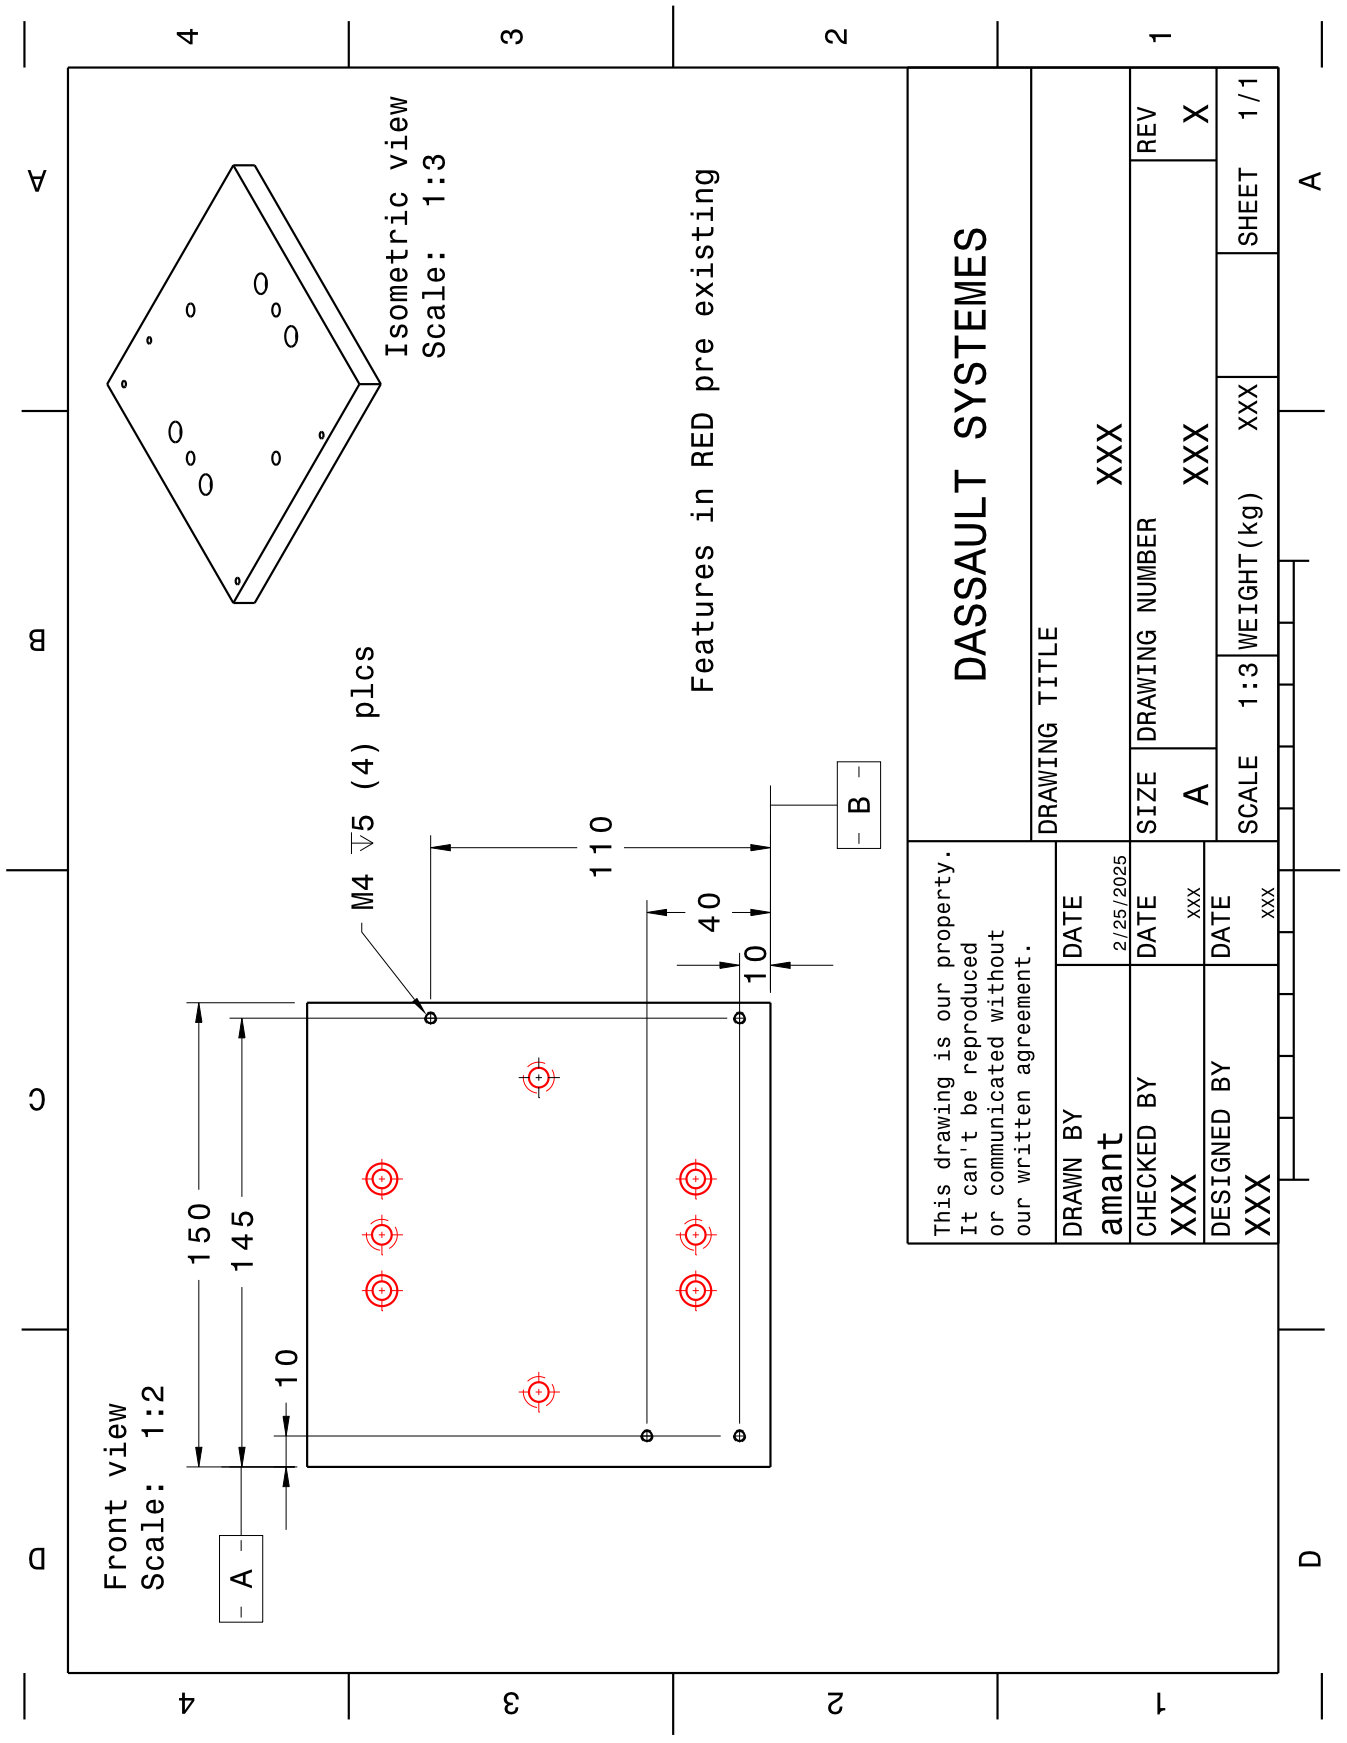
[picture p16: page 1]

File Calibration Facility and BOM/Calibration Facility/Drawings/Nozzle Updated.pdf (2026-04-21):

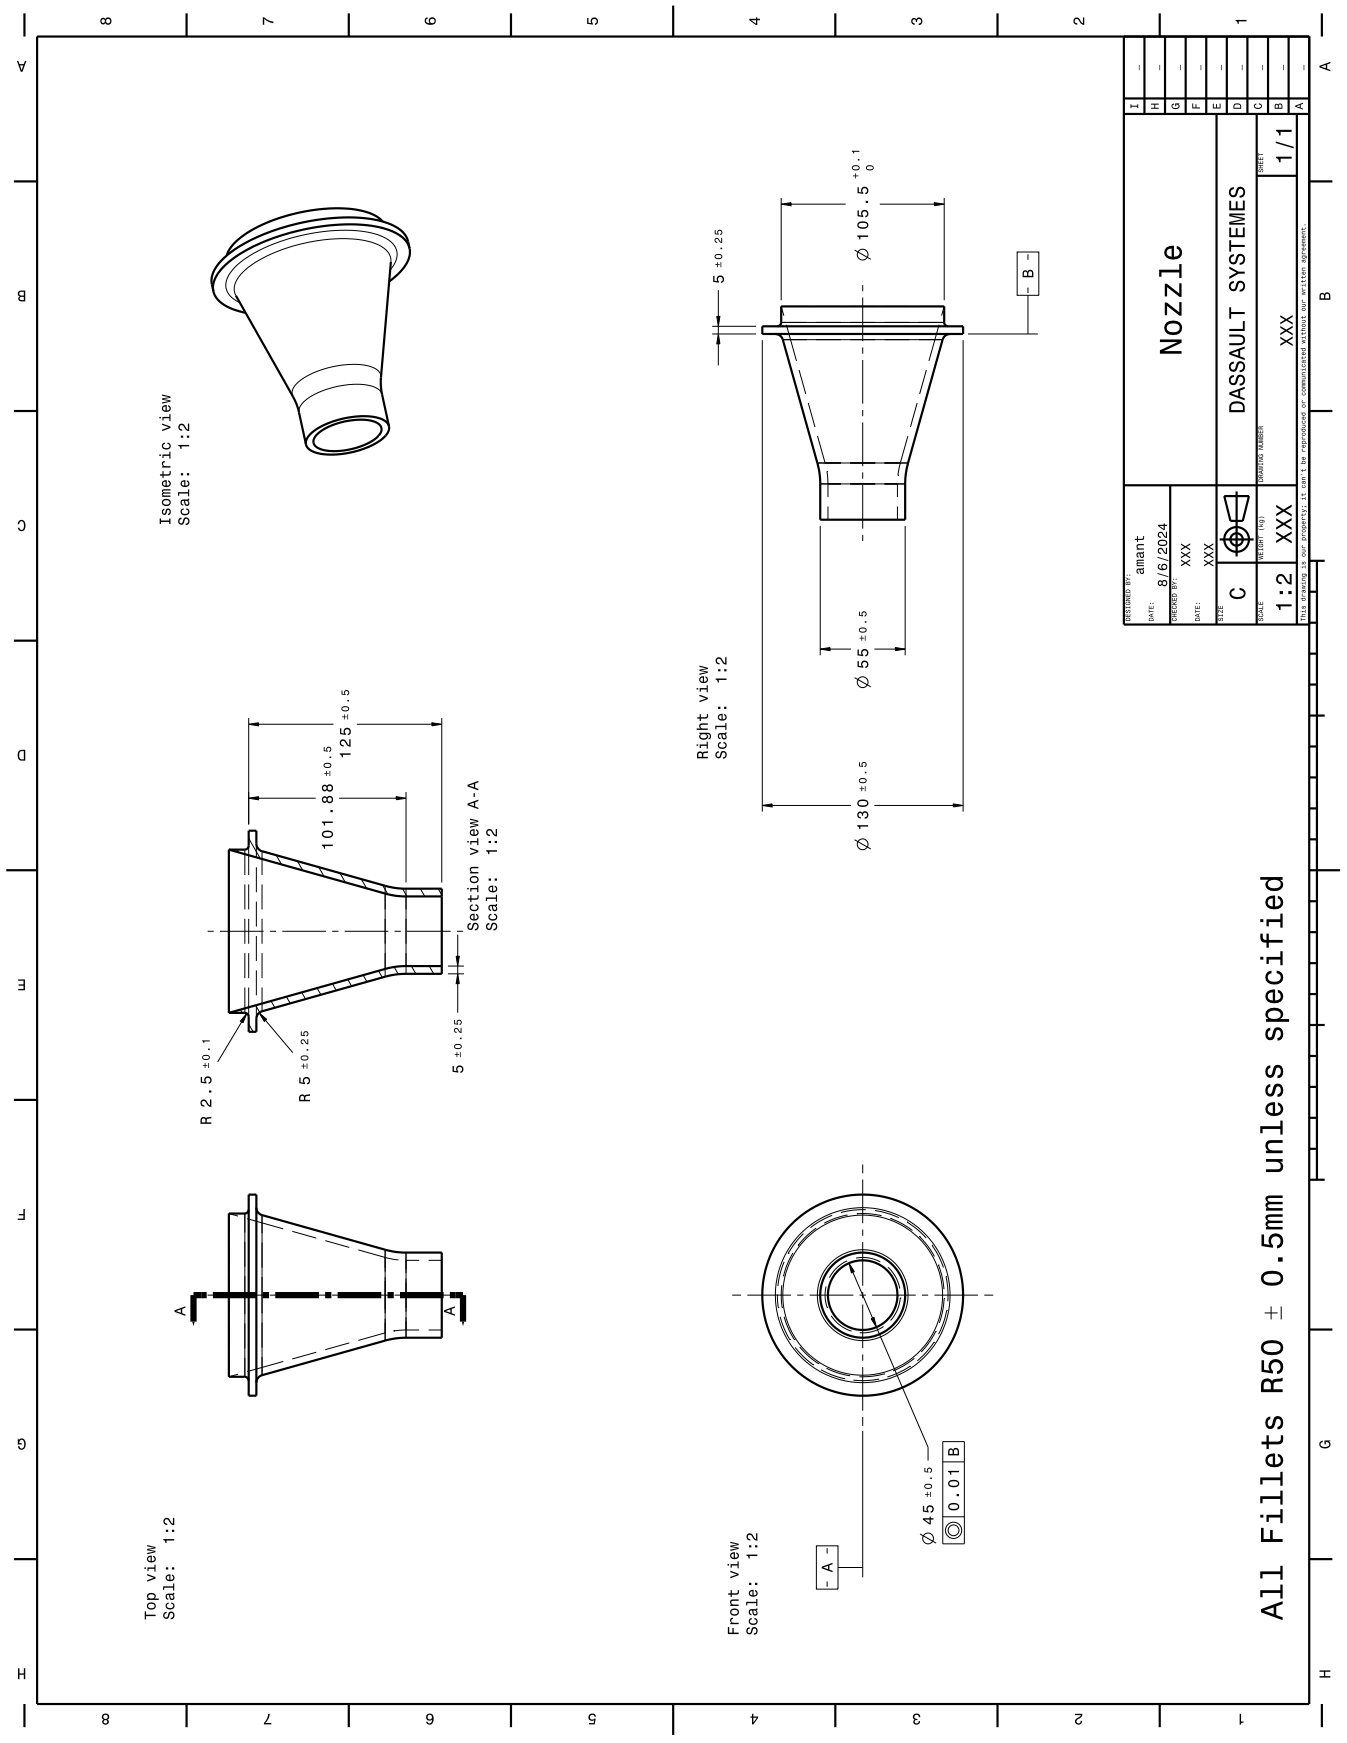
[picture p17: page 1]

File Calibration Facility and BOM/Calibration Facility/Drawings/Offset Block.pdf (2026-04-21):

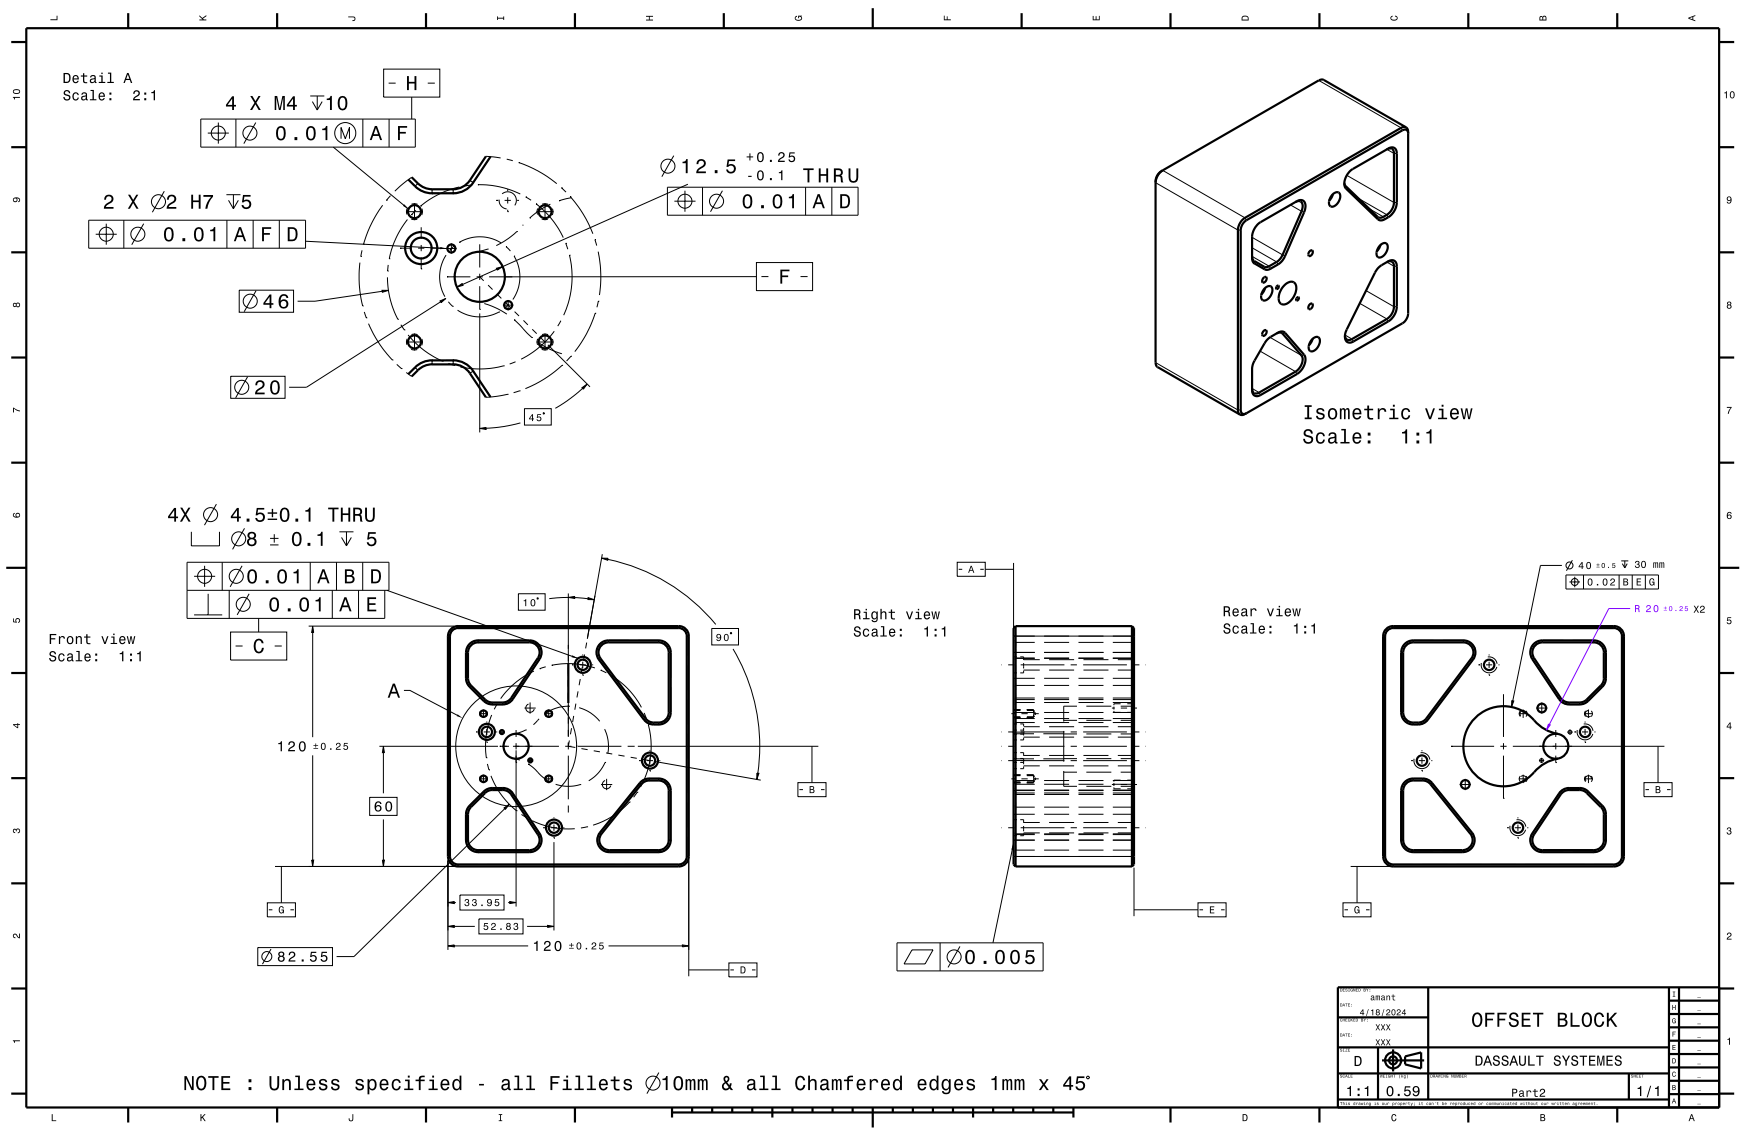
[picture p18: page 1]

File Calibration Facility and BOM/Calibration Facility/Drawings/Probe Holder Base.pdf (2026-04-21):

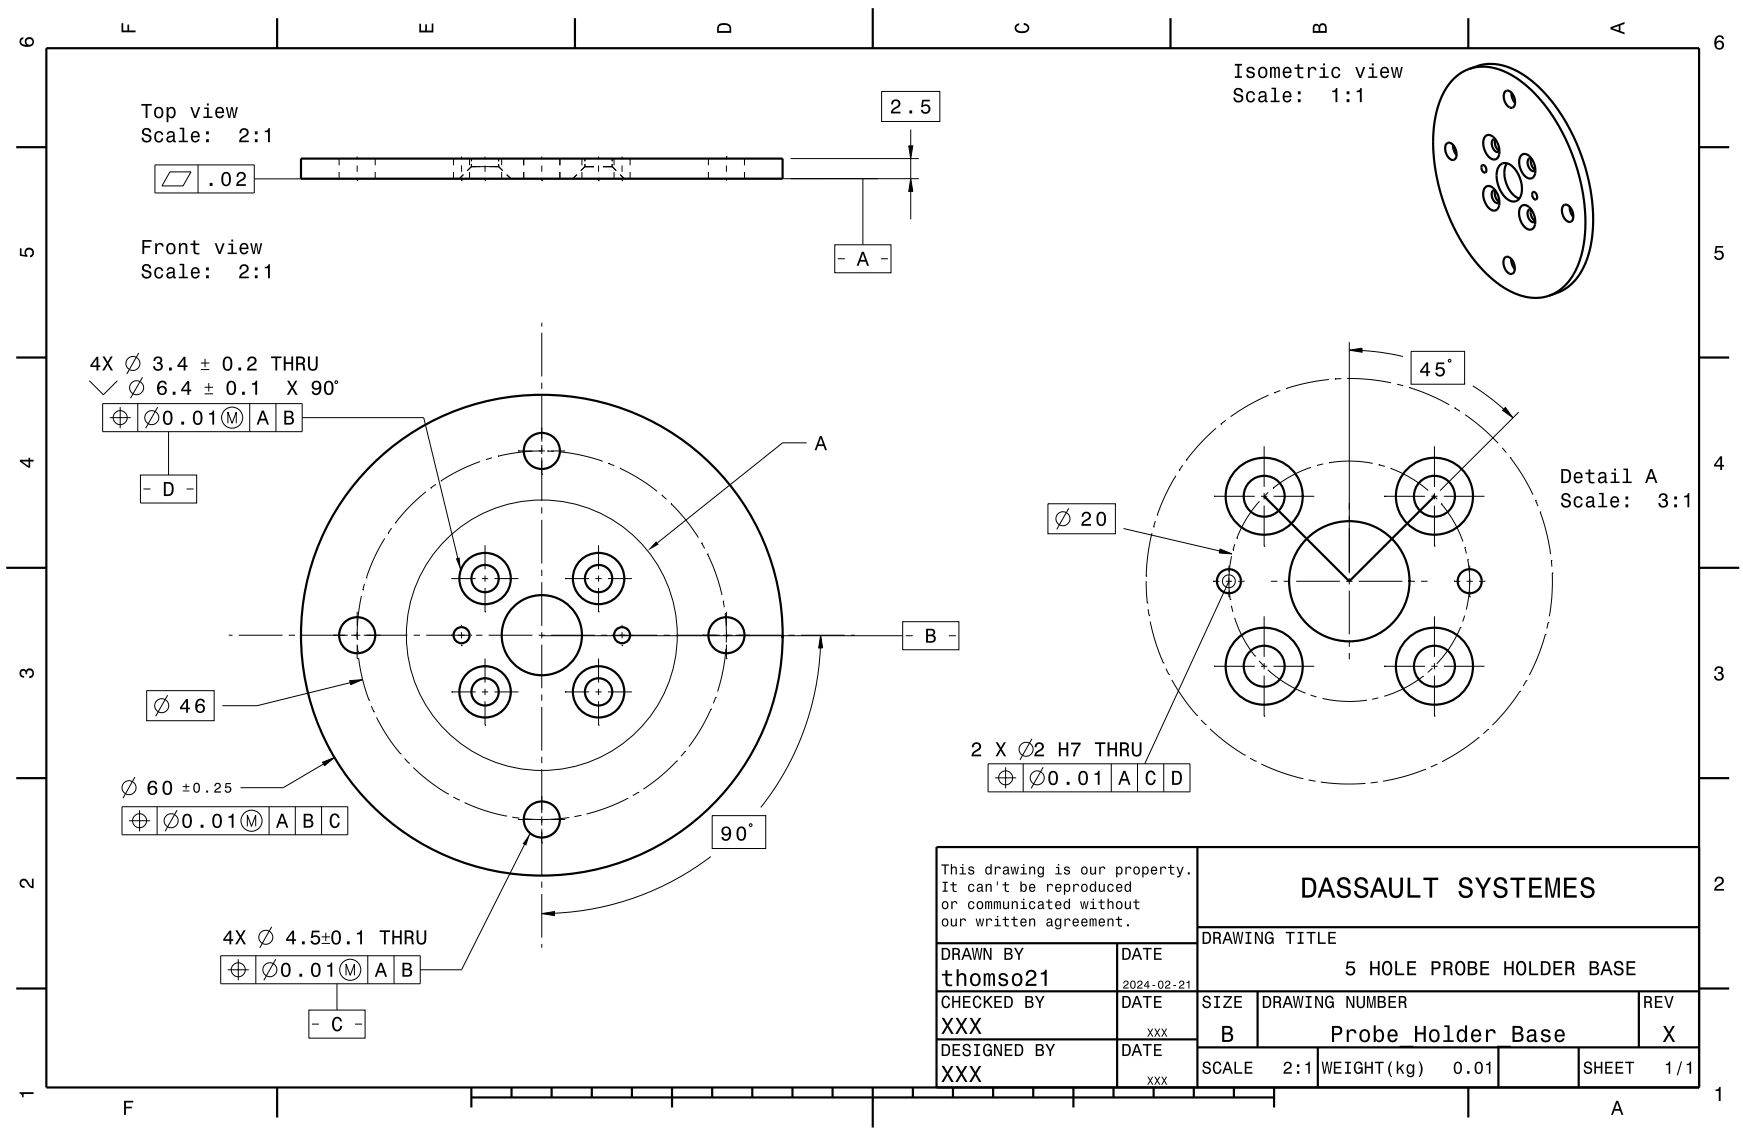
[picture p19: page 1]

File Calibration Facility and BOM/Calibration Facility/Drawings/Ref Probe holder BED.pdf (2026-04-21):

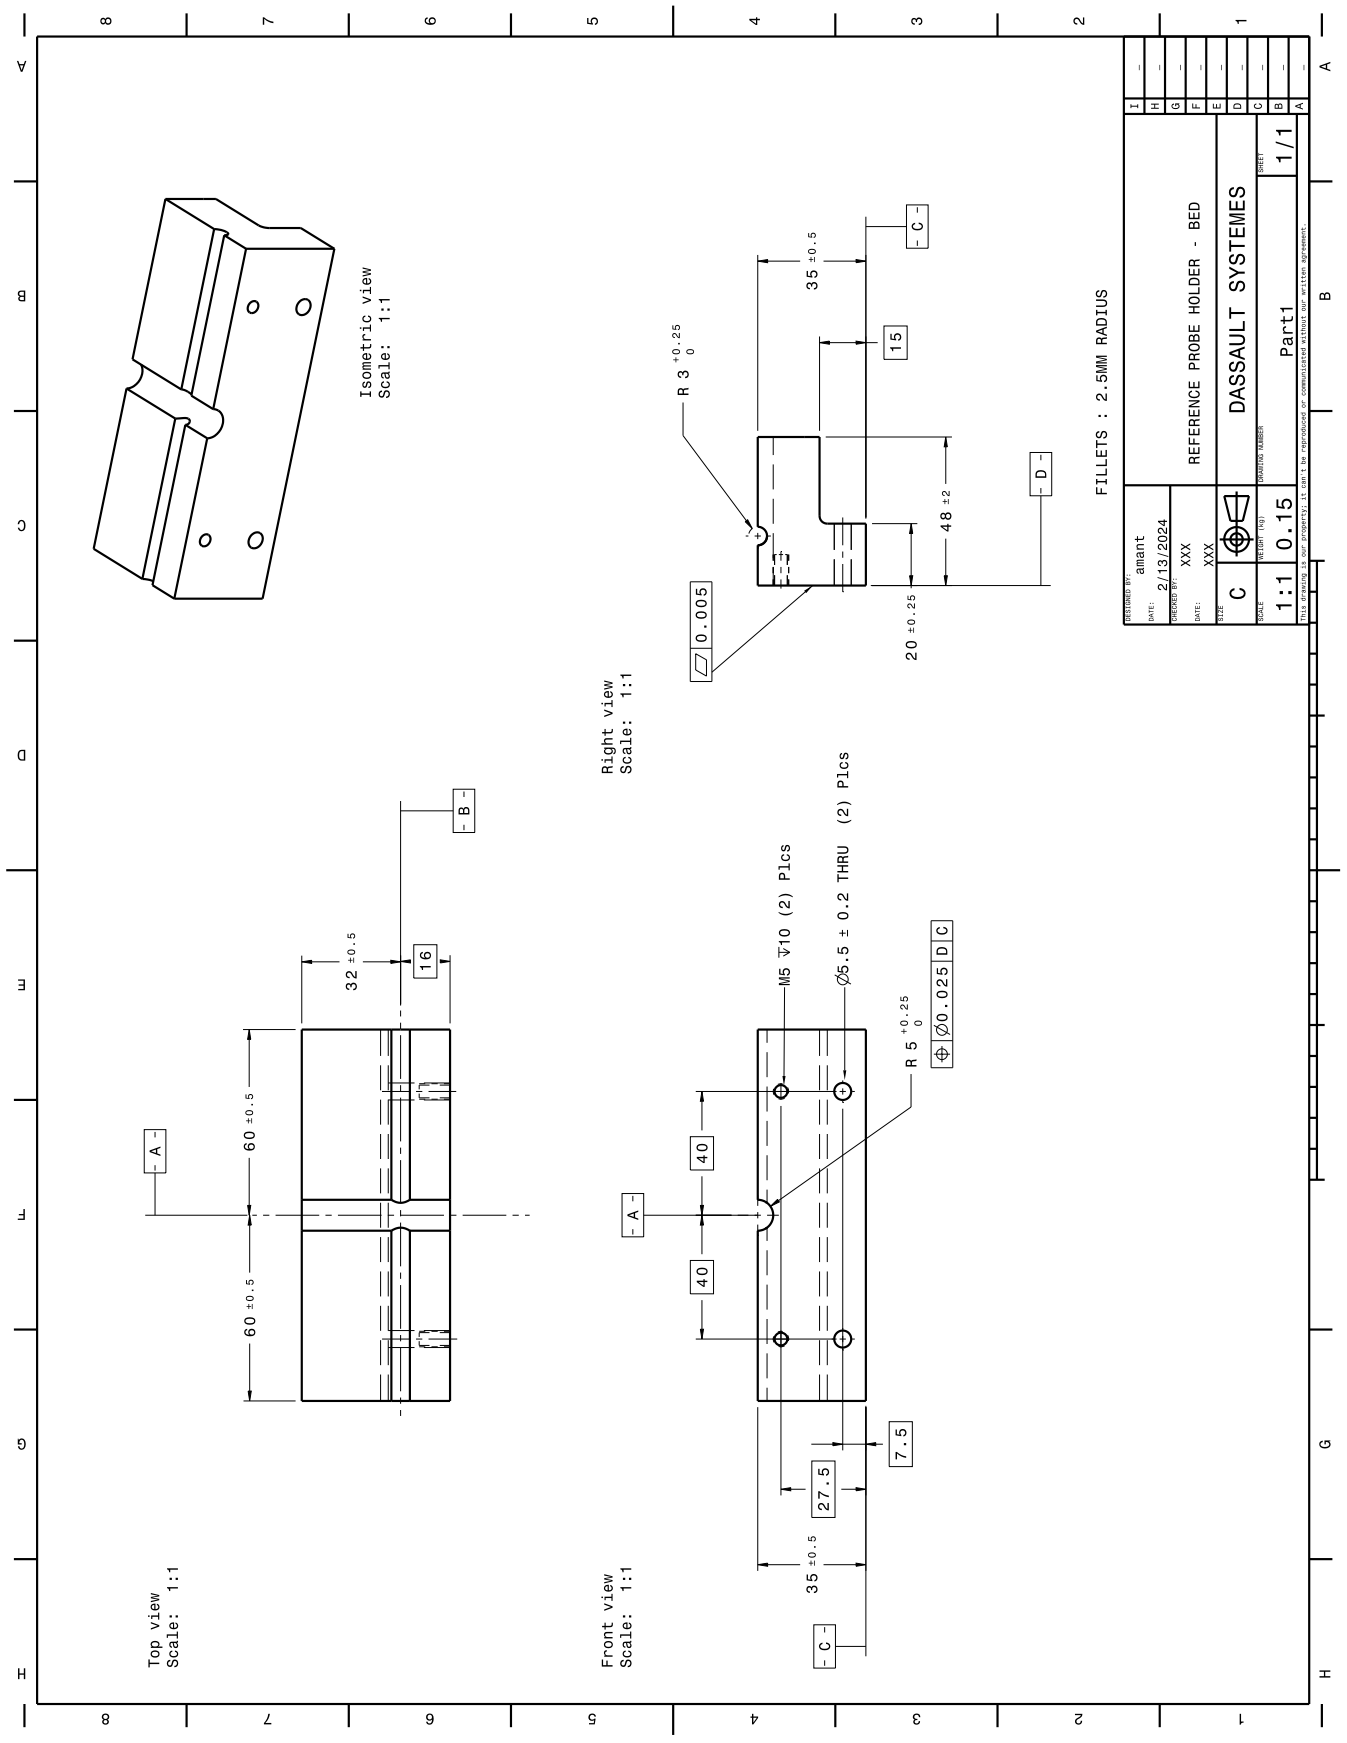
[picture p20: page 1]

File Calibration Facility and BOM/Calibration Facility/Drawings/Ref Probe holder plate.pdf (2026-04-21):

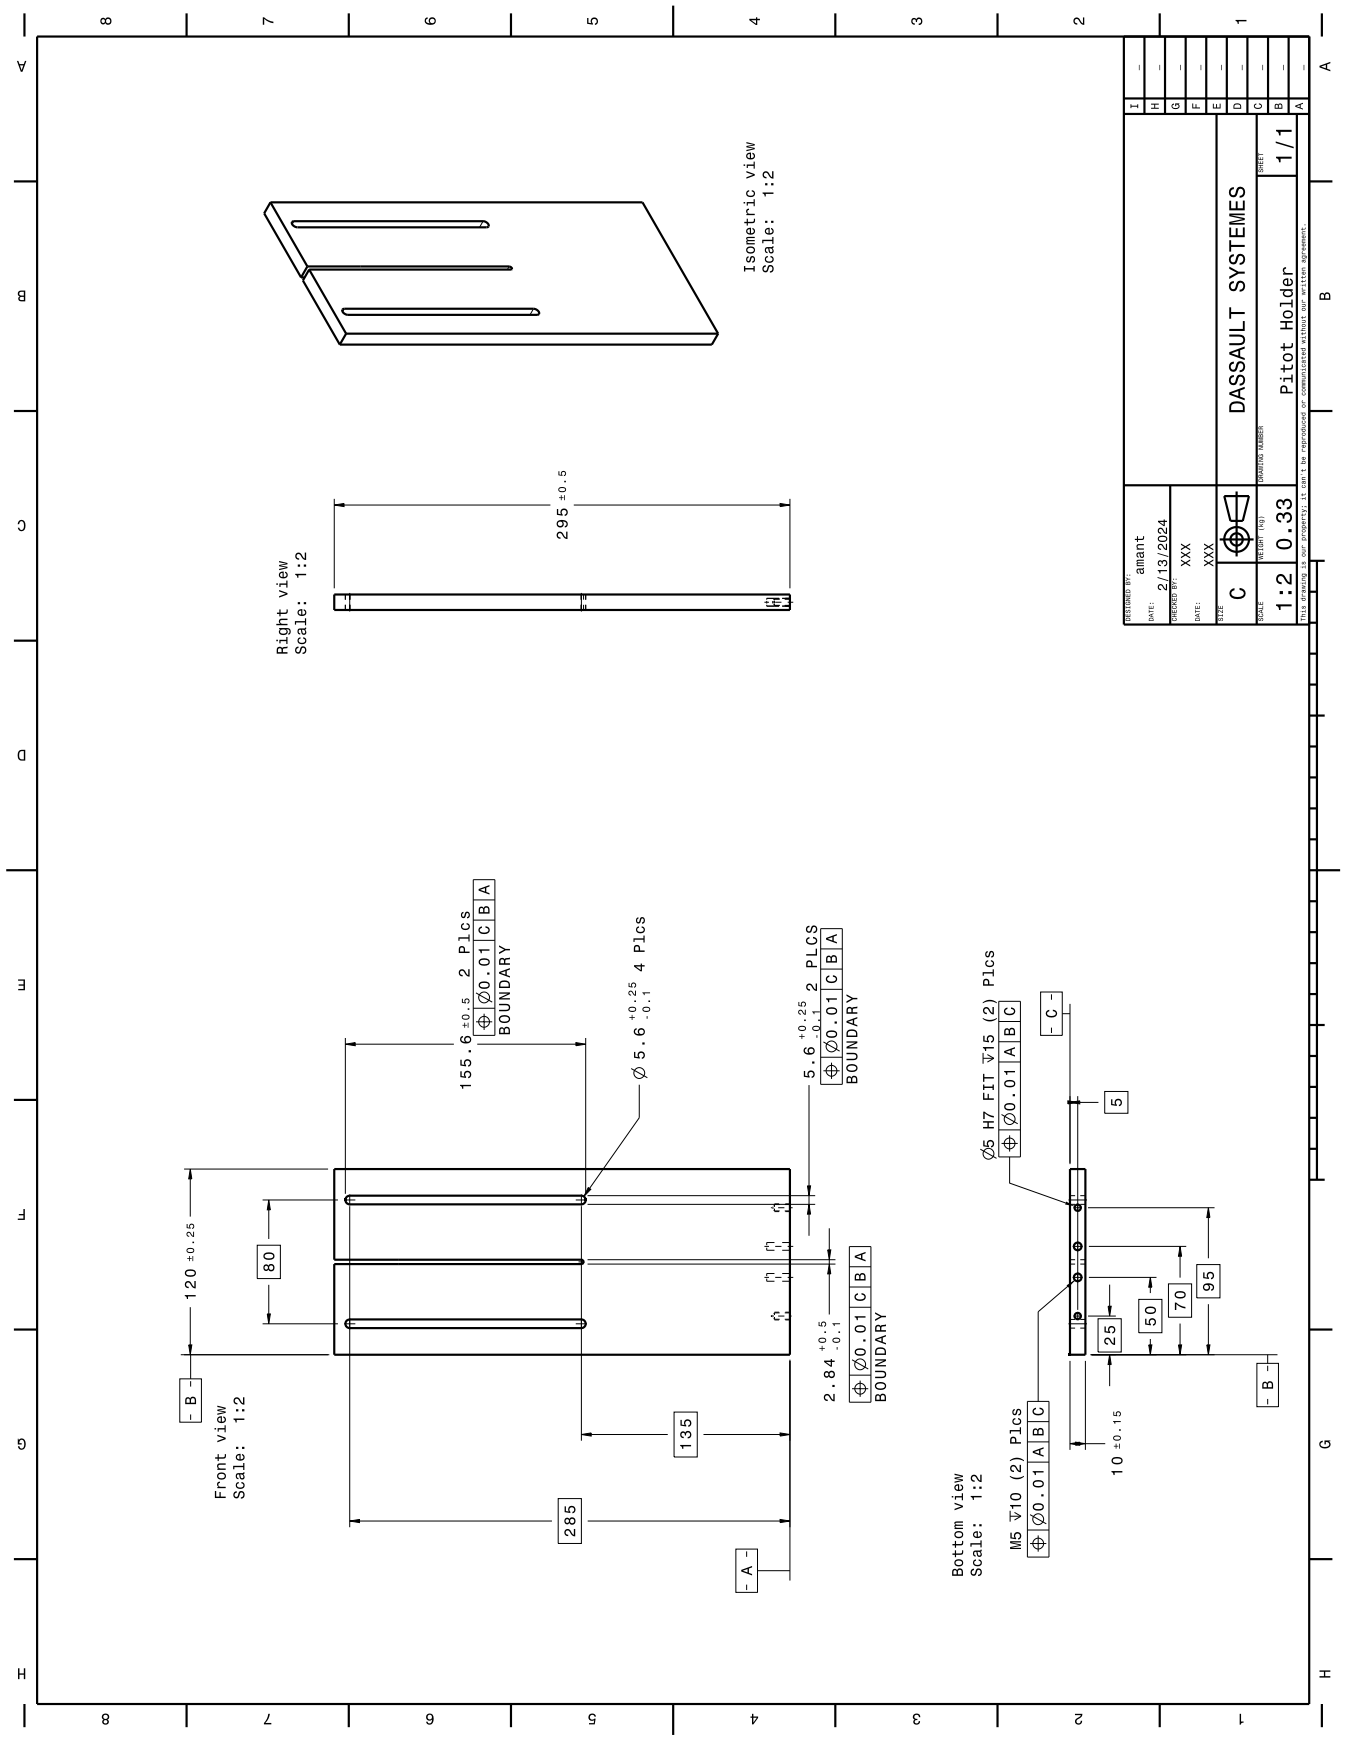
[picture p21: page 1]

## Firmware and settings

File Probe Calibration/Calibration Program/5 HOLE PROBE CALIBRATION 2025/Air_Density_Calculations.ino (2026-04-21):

#include <Wire.h>
#include <SPI.h>
#include <Adafruit_BMP280.h>
#include "DHT.h"

// Pin Definitions for BMP280 SPI
#define BMP_SCK  (13)
#define BMP_MISO (12)
#define BMP_MOSI (11)
#define BMP_CS   (10)

// DHT11 Sensor Pin and Type
#define DHTPIN 2
#define DHTTYPE DHT11

// Constants for air density calculation
const float Rd = 287.05;  // Specific gas constant for dry air (J/(kg·K))
const float Rv = 461.5;   // Specific gas constant for water vapor (J/(kg·K))

// Create instances of BMP280 and DHT11
Adafruit_BMP280 bmp(BMP_CS, BMP_MOSI, BMP_MISO, BMP_SCK);
DHT dht(DHTPIN, DHTTYPE);

void setup() {
  Serial.begin(9600);
  
  // Initialize BMP280
  if (!bmp.begin()) {
    Serial.println(F("Could not find a valid BMP280 sensor, check wiring!"));
    while (1) delay(10);
  }

  // Initialize DHT11
  dht.begin();

  // Set BMP280 sampling parameters
  bmp.setSampling(Adafruit_BMP280::MODE_NORMAL,     // Operating Mode
                  Adafruit_BMP280::SAMPLING_X2,     // Temp. oversampling
                  Adafruit_BMP280::SAMPLING_X16,    // Pressure oversampling
                  Adafruit_BMP280::FILTER_X16,      // Filtering
                  Adafruit_BMP280::STANDBY_MS_500); // Standby time
}

void loop() {
  // Read temperature from BMP280
  float bmpTemperatureC = bmp.readTemperature();
  float bmpTemperatureK = bmpTemperatureC + 273.15; // Convert to Kelvin
  
  // Read pressure from BMP280
  float pressure = bmp.readPressure(); // in Pa

  // Read humidity from DHT11
  float humidity = dht.readHumidity();

  // Check if DHT11 reading failed
  if (isnan(humidity)) {
    Serial.println("Failed to read from DHT sensor!");
  } else {
    // Calculate saturation vapor pressure (e_s) in hPa
    float es = 6.1078 * pow(10, (17.27 * bmpTemperatureC) / (bmpTemperatureC + 237.3));

    // Calculate actual vapor pressure (p_v) in Pa
    float pv = es * (humidity / 100.0) * 100; // Convert from hPa to Pa

    // Calculate partial pressure of dry air (p_d) in Pa
    float pd = pressure - pv;

    // Calculate air density (rho) in kg/m^3
    float airDensity = (pd / (Rd * bmpTemperatureK)) + (pv / (Rv * bmpTemperatureK));

    // Send data as a CSV line: "Temperature,Humidity,Pressure,AirDensity"
    //Serial.print(bmpTemperatureC);
    //Serial.print(",");
    //Serial.print(humidity);
    //Serial.print(",");
    //Serial.print(pressure);
    //Serial.print(",");
    Serial.println(airDensity);

    // Delay to achieve 0.5 Hz (2 seconds)
    delay(2000);
  }
}

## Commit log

2026-04-21 Files related to the calibration of Windsor Probe- Probe number 1
    [5Hole_Probe_Holder_New_L.CATPart, 5Hole_Probe_Holder_New_R.CATPart, 5_Hole_Probe_Assembly.CATProduct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]
2026-06-10 Create Calibration Data and Maps
2026-10-07 On Axis Calibration Data for all 3 probes at ReMAx - Use them for measurements
    [Calibration Data.xlsx, Mean Data.xlsx, P1_ReMax_R1.xlsx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]
